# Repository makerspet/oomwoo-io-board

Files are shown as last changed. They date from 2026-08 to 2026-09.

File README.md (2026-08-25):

<div align="center">

# OOMWOO I/O Board

*Open-source robot vacuum you build yourself.*

Raspberry Pi CM4/CM5 socket · STM32G473 MCU · Motor drivers · Sensors · 2x MIPI cameras · 4S charging · KiCad





</div>

Part of [OOMWOO open-source robot vacuum](https://github.com/makerspet/oomwoo) project.

oomwoo_main_pcb_placement

Get [MCU firmware](https://github.com/makerspet/oomwoo-io-firmware/).

## Architecture notes

Consumer vacuums typically split compute into CPU and MCU. The MCU ([real examples](https://robotinfo.dev/)) controls
- all motors - driving wheels, suction fan, side brushes, mop motors, mop lift servos, pump and so on
- all sensors except below - IR cliff, IR side proximity, IR docking, wheel drop, bumper (IR or micro-switches), motor encoders, ultrasonic carpet sensor
- all push buttons
- 2D LiDAR motor RPM
- power - battery charging, motors power on/off
- all safety sensors - overcurrent for all motors (cheap vacuums ignore overcurrent sensing)

I/O board also provides audio encoders/decoders, amp, speaker (connector), mics (if any).

CPU receives
- 2D LiDAR data over serial port
- IMU (sometimes IMU gets forwarded via MCU) over SPI/I2C
- cameras (2x MIPI for visual obstacle avoidance)

MCU (and CPU) are usually always active. This allows the user to start cleaning at any time (especially via app remotely). Exceptions:
- no power (battery dead and no dock power)
- user explicitly shut down the vacuum by long-pressing the power button

The MCU's overarching constraint is to ensure robot safety. This is necessary to pass CE mark tests. Here is how MCU ensures safety:
- MCU firmware uses FreeRTOS or similar, static memory allocation, watchdog, guaranteed reaction time
- MCU acts as watchdog for CPU, resets CPU if CPU becomes unresponsive
- MCU connects to CPU over serial using a custom serial protocol ([concrete example](https://github.com/codetiger/VacuumRobot)). No micro-ROS to reduce dependencies, prevent bugs from updated 3rd party libraries slipping into safety-critical MCU firmware.
- MCU shuts down some (or all) motors when MCU detects overcurrent (brush stuck)
- MCU shuts down all motors (including power to all motors) when CPU becomes unresponsive (to prevent CPU sending garbage commands to MCU)
- MCU monitors battery charging, shuts it down when needed (battery too hot)
- MCU stops driving wheel motors when bumper sensors activate
- MCU tests motors, sensors
- MCU does not depend on CPU
- MCU toggles watchdog GPIO; otherwise an external-to-MCU circuit shuts down motor power

Consumer vacuums place CPU and MCU on the same PCB board. Since OOMWOO has to be hackable, it seems best to separate I/O from the compute. Therefore, this I/O board needs to have
- MCU and programming header
  - likely STM32G070RBT6 because it has 56 GPIOs, 16 ADC channels, costs $1 at JLCPCB, has LQFP package for easy PCBA - a rare combination
  - see tentative [I/O board spec](https://github.com/makerspet/oomwoo-io-board/blob/main/docs/SPEC.md)
- all vacuum motor drivers (with connectors), driven by the MCU
  - cliff, side proximity, docking, bumper, carpet, water tank full/empty, dust bin present, motor overcurrent, motor encoders
- MCU connected to all sensors (except those handled by CPU like LiDAR serial, MIPI cameras I/O, IMU); sensor connectors
- control circuit for 2D LiDAR's motor (controlled by MCU)
- battery charging, power management (motors power on/off, charging on/off, power shut down), power for CPU compute module (see below)
- push buttons (home, power, etc.) and UI LEDs
- dock connector (dock power, sense dock present)
- USB power for charging; USB for serial shell, etc.
- audio encoder/decoder, audio amp, mics (if any)
- SD card for hacking, cheap large storage
- connect IMU FSYNC to MCU to synchronize MCU timestamps with IMU data streaming to CPU

Consumer vacuums usually don't have a CPU fan/heatsink because the vacuum's suction fan can (indirectly) cool the CPU/MCU PCB. Therefore, no CPU fan on this I/O board.

As far as compute - currently it seems best to use a Raspberry Pi CM4/CM5 compute module. Why?
- CM4/CM5 modules cost a bit less than a full Raspberry Pi 4/5
- CM4/CM5 have lower profile/height vs a full Raspberry Pi 4/5, important to keep vacuum cleaner slim
- there are plenty of 3rd party compute modules pin-compatible with CM4/CM5, making the compute swappable, hackable
  - 3rd party compute modules with NPUs are especially interesting because we need NPU for real-time camera-based obstacle detection

Compute module headers should expose
- 2x MIPI camera I/O
- 1x serial for CPU-MCU comms
- 1x serial for CPU-LiDAR comms
- 1x SPI (or I2C) for CPU-IMU comms
- audio (digital?) I/O
- power from I/O board to CM
- a few TBD GPIOs
  - MCU GPIO to reset CPU

This board should be designed using an open-source PCB tool (KiCad seems like a good choice).

## License

[Apache License 2.0](LICENSE).

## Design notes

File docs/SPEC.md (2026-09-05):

# OOMWOO I/O Board spec (work in progress)

See [vacuum BOM](https://github.com/makerspet/oomwoo/blob/main/BOM.md) for details.

## Motors

Most motors draw power directly from the 4S battery (not via a DC-DC converter). The battery is 14.4V nominal, 12V discharged and 16.8V fully charged.

| Type | Qty | Spec |
| --- | --- | --- |
| Drive wheel | 2 | DC 14.4V 19 Ohm, measured 0.14A no load / 1.7A stall, H-bridge DRV8231, DRV8871 or similar |
| Suction fan | 1 | BLDC 14.4V, measured 1.7A free / 2.7A intake blocked (BL24131607 at 15V), high-side load switch P-FET, PWM input to fan, FG feedback to STM32 |
| LiDAR | 1 | 5V 0.35A max, Mabuchi-style RF-500TB-14350 or similar, low-side load switch N-FET |
| Main brush | 1 | DC 14.4-15V, measured 0.26A no load / 3.5A stall, PRI-390SV-24100, JLS-395PH-2248A, RS-390WM-3107GCF or similar (bridge or FET TBD) |
| Side brush | 1 | DC 14.4V, 1.3A stall estimated (not yet measured), RC500-KW/14440/DV, PR-500EV-14440 or similar (bridge or FET TBD) |
| Mop | 2 | GM-RS385Y-24065 or similar, DC 14.4V |
| Mop lift | 1 | Likely MG90S servo |
| Mop arm | 1 | Likely MG90S servo |
| Water pump | 1 | TBD |
| Side brush arm | 1 | Likely MG90S servo |

Motor pinouts

```
Roborock S5 Max wheel assembly - JST ZH 1.5mm male 7p (mates board f)
  0.14A no load, 1.7A stall at 14.4V
  pin 7 wheel-drop-switch on
  pin 6 wheel-drop-switch com
  pin 5 orange Hall 3.3-5V
  pin 4 blue Hall signal OUT, open collector
  pin 3 brown Hall GND
  pin 2 MOT-
  pin 1 MOT+

BL24131607 suction fan DC 14.4V; 15V 1.7A unobstructed, 2.7A intake obstructed
 JST PH2.0 female 5p (mates m-m fan-to-board cable)
 pin 5 +  (VMOT)
 pin 4 -  (GND)
 pin 3 SP (PWM)
 pin 2 FG (TACH)
 pin 1 ID (20K pulldown to GND to detect fan presence, I believe)

DC 14.4-15V 4S suction fans:
- 20N704R990F
- MSD-C-3
- MSD-D
- 20N709U020
  JST PH2.0 female 4p (mates m-m fan-to-board cable)
  pin 4 VMOT
  pin 3 GND
  pin 2 PWM, low == off; drive at 5V?
  pin 1 TACH open collector

22N704V160 suction fan DC 14.4V - JST PA 2mm 5 pin (needs male)

BL27302101 suction fan DC 14.4V - JST PA 2mm 6-pin (needs male)
  pin 1 VCC
  pin 2 VCC
  pin 3 GND
  pin 4 GND
  pin 5 PWM
  pin 6 FG (TACH)

BL24131616 suction fan DC 14.4V - JST PA 2mm 5 pin  (needs male)
  pin 5 VM
  pin 4 GND
  pin 3 PWM
  pin 2 FG (TACH)
  pin 1 ID

MSD-G-V1 suction fan - LHE MX3.0 2x2 (4-pin) 3mm pitch with latch male (aka Molex Micro-Fit 3.0)
```

Main brush Roborock S50 S51 S55 XIAOWA C10 0.26A no load, stall 3.5A at 14.4V

## Cliff sensors

JST PAD 2.0mm 8x2 housing, mates JST S16B-PHDSS, JST B16B-PADSS.

## Compute + Camera

- 2x 15-pin ArduCam-style connectors for OV5647
- TODO add USB to I/O board

Undecided TODO 
- maybe provision an M.2 slot, route a PICe lane, populate later - to experiment with NPU accelerator(s) like Hailo
- USB-C 3.0+, CM5 only - to experiment with accelerator(s) like Coral TPU
- Keep the compute socket able to take an integrated-NPU module too (Radxa CM5) or premium-upgradeable (CM5 + M.2 Hailo).
- Flag it to the PCB contractor as a design item: M.2 E-key (WiFi) + an M.2 M-key/PCIe (NPU or NVMe), PCIe lane routing, and the thermal path for a few-watt accelerator in a suction-cooled enclosure

## Charging

View [BRR-2P4S-5200FL battery datasheet](https://images.thdstatic.com/catalog/pdfImages/55/55d2f7f6-2ed9-44ed-ab4e-fb20d231c897.pdf) as a sample.

```
Battery BRR-2P4S-5200 14.4V nominal - 4-pin 3mm pitch with latch male LHE MX3.0 (C3001-H04), Molex Micro-Fit 3.0
[o66o] 4321 BAT+ 10.7K/NTC 0.62M/ID GND
```

### Robot

- the robot has 2 power inputs: USB-C and dock
  - robot receives 20-24V fixed DC from the dock
  - USB-C power use PD, request 20-24 V minimum (to step it down to 4S battery)
  - optional PPS
  - if a low-power USB-C 5V, 9V or 15V brick source is attached (no 20V/PPS), either charge slowly (optional) through a boost path or cleanly refuse and signal "insufficient charger" rather than misbehaving
- robot requires 65W minimum input (from the dock) with system power-path charger (a charger IC with a SYS rail)
  - support the vacuum charging and Raspberry Pi running simultaneously
  - assume Raspberry Pi is always on (to handle user access over Wi-Fi at any time)
  - Pi 5 worst case ~25 W (5 V/5 A) + housekeeping ≈ up to ~25–30 W
  - Healthy charge ~40 W (~0.5C into the 75 Wh pack)
  - ~65–70 W total
- cap charge at ~0.5C regardless of charging adapter power

### Dock

- the dock is powered from an external certified 24/25.2 V DC brick (~200–350 W)
  - use external brick for safety, the dock enclosure only ever sees 24 V DC
  - reuse a 25.2 V stick-vac motor for auto-empty, e.g. Dreame M10-E-4 25.2 V/310 W
- the dock has only 2 contacts: DOCK+ and GND
  - dock contacts feed a fixed 24V+ DC
  - the dock detects load/robot presence, energizes DOCK+ only when robot is detected (reliably, after a couple of seconds)
  - dock contacts are spring loaded, gold-coated pogo pins ≥4 A, placed rear-vertical, above water line
- ambient fan(s) for mop drying
  - no hot mop dry for now
- 2x water pumps: clean-feed + dirty-evacuate
  - diaphragm, 12–24 V
- dock PCB
  - ESP32 (WiFi + BLE + control)
  - Pump/fan drivers (brushed DC)
  - IR beacon LEDs + driver
  - robot/load presence-detect + charging contact energize FET
  - Level sensors (float/capacitive) clean-low, dirty-full
  - high-side FET for auto-empty blower
  - fuse, DC inlet, TVS
  - buck DC-DC 24V to 5V, 3.3V for ESP32, sensors

### Power path

Standard capability of power-path charger ICs - TI bq25 family and similar.

```
USB-C 20V ─► [PD sink] ─► [power-path charger] ─┬─► SYS rail ─► 14.4→5V buck ─► Pi (always-on)
                                                └─► charges 4S pack
Battery ────────────────────────────────────────┘ (supplements SYS if input insufficient)
```

- Docked: the Pi runs from the input via SYS; the battery charges from the surplus; once full, charge current → 0 and the Pi keeps running off input — no needless battery cycling while docked (also a longevity win).
- Undocked: SYS seamlessly falls back to the battery — the Pi never browns out during the handoff. This is exactly what makes "pause → return to charge → resume" and "app connects anytime" work cleanly.
- Input-limited: if only a weak brick is attached, the battery supplements SYS so the Pi stays up, and charge current backs off. Graceful degradation for free.

Details

1. 65 W = 20 V / 3.25 A → e-marked cable required. Above 3 A / 60 W, USB-C needs a 5 A e-marked cable. Unavoidable at 65 W (20 V is PD's max fixed voltage) — just document it. 65 W bricks ship with an e-marked cable anyway.
2. Dynamic power management (VIN/IIN-DPM): the charger must throttle charge current to keep total draw within the negotiated PD budget, prioritizing the Pi/SYS load. Standard on power-path chargers.
3. Cap charge current at ~0.5C (~2.6 A into the pack) for cell life, regardless of surplus — don't let a big brick fast-charge the cells.
4. Two DC inputs, one charger: the robot's own USB-C port and the dock contacts both present ~20 V DC → OR them into the charger's VBUS with priority/ideal-diode selection (both are the same voltage, so it's clean).
5. Dock side: dock has its own PD sink + 65 W brick, passes ~20 V to the contacts. At 20 V, 65 W ≈ 3.25 A over the contacts → size the pogo/spring contacts for ~4 A with margin.

Net spec

1. USB-C PD, 65 W minimum (20 V / 3.25 A), on both the robot port and the dock (each with its own PD sink); e-marked cable expected.
2. Power-path 4S charger with a SYS rail feeding the Pi's 5 V buck, so the Pi is always-on from input when docked and from battery when not, with seamless handoff and battery-supplement under load.
3. DPM + 0.5C charge-current cap; OR the two DC inputs into one VBUS; dock contacts rated ~4 A.

## LiDAR pinouts

```
X-WPFTB-V2.6.2 PCB marking - JST GH 1.25mm 4-pin female (needs m)

D-WPFTBCD-V1.0.1 PCB marking - JST GH 1.25mm 4-pin female (needs m)

LDROBOT LD14P lookalike - JST GH 1.25mm 4-pin female (needs m)

Mystery mini - JST GH 1.25mm 5-pin female (needs m)
```

## Front sensors module board

- 2x VL53L7CH (or VL53L7CX) 60° horizontal FoV each
  - each turned 30° left, right to cover 120° horizontal FoV
- 2x OV5647, 5M wide-angle for stereo depth + object recognition
  - off-the-shelf breakout boards for now
  - possibly $2 imaging ICs later
- NIR illumination LEDs with a projection pattern
- breaks into multiple PCBs using holes
  - central - 2x TSOP38238 (separated by a baffle) for dock homing
  - left - VL53L7CH pointed 30° left
  - right - VL53L7CH pointed 30° right
  - stereo depth camera 2x OV5647 with NIR illumination LEDs

## Side sensors module board

- TSOP38238 for dock detection
- consumer vacuums use analog Sharp short-range distance sensor
  - use VL6180V1NR/1 C2655167 $1.03 100pcs 18° FoV diagonal? Obsolete, similar to VL53L4CD
  - use VL53L0CX GY-530, TMF8806 or similar instead? Dust may be an issue.
  - VL53L0CXV0DH/1 C91199 $2.11 100pcs
  - VL53L4CDV0DH/1 C3178291 $2.19 100pcs

## Sensors

- VL53L7CH
  - Arduino library https://github.com/stm32duino/VL53L7CH
  - hookup schematic https://eu.mouser.com/en/new/stmicroelectronics/stm-vl53l7ch-tof-sensor
  - LPn pin sets I2C address

## Pump

- 6V DC motor, peristaltic; ~0.6A rated, 1A max
- make DC settable by replacing resistors

## GPIO

Please see the [PCB schematic](https://github.com/makerspet/oomwoo-io-board/tree/main/kicad/PDF) for up-to-date GPIO list.

TODO before layout/fabrication: confirm whether GPIO entries 36 and 46 are intentionally separate bumper inputs or a duplicate label.

## Carpet sensors

- Read [sourcing notes](https://makerspet.com/blog/how-to-source-bom-for-oomwoo-open-source-vacuum-robot/#carpet-sensor).
- 290KHz ultrasonic piezoelectric analog, likely [this one](https://htwsensor.en.made-in-china.com/product/HfMYgjwoZxVh/China-300kHz-Carpet-Material-Recognition-Sensor-for-Robotic-Vacuum-Cleaner-Ultraosinc-Sensor.html)

How to drive
- ≥12V DC stabilized per spec (not 4S battery directly?)
- connect to MCU ADC input
  - use STM32G473VCT6 internal op-amp as echo input (AC via a cap)
  - clamp amplitude to 3.3V (back-to-back clamp diodes, series resistor)
  - bias the MCU internal op-amp to Vref/2 using MCU internal DAC
  - configure ADC pre-amp gain, PGA mode (op-amp bandwidth is 10MHz)
  - configure op-amp to output signal to internal ADC channel
- FET half-bridge driven by MCU
  - drive the sensor for a brief while
  - tristate both FETs
  - measure using ADC, calculate return amplitude
  - calibrate return amplitude when docked
- 2-pin connector "1.25mm Y" per spec, exact model unclear
  - not Molex PicoBlade 1.25mm, not JST GH 1.25mm

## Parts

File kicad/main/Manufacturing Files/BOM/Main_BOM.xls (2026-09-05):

Comments | Designator | Footprint | LCSC | Note
150pF/50V | C7,C101,C105 | Capacitor_SMD:C_0603_1608Metric
22pF/50V | C34,C35 | Capacitor_SMD:C_0603_1608Metric
18pF/10V | C39,C42 | Capacitor_SMD:C_0603_1608Metric
330pF/25V | C47,C58 | Capacitor_SMD:C_0603_1608Metric
47nF/50V | C75,C79,C110 | Capacitor_SMD:C_0603_1608Metric
1nF/50V | C77,C125,C126 | Capacitor_SMD:C_0603_1608Metric
10k | R1,R18,R21,R22,R23,R25,R31,R32,R34,R36,R38,R39,R41,R42,R44,R45,R49,R50,R51,R52,R81,R92,R93,R110,R132,R142,R150,R152 | Resistor_SMD:R_0603_1608Metric
47k | R2,R7,R61,R62,R151 | Resistor_SMD:R_0603_1608Metric
100k | R3,R4,R8,R10,R11,R13,R16,R17,R20,R27,R29,R40,R43,R48,R53,R54,R55,R57,R58,R59,R115,R116,R118,R128,R130,R133,R135,R138,R139,R153 | Resistor_SMD:R_0603_1608Metric
2.2k | R5,R6,R15,R149 | Resistor_SMD:R_0603_1608Metric
0 | R9,R12,R19 | Resistor_SMD:R_0603_1608Metric
1k | R14,R28,R37,R65,R77,R78,R79,R82,R85,R113,R120,R121,R140 | Resistor_SMD:R_0603_1608Metric
330 | R30,R35 | Resistor_SMD:R_0603_1608Metric
20k | R47,R131,R147 | Resistor_SMD:R_0603_1608Metric
30.31k | R60 | Resistor_SMD:R_0603_1608Metric
10 | R64,R73,R74,R80,R94,R95,R96,R101,R117,R141,R146,R154 | Resistor_SMD:R_0603_1608Metric
100 | R75,R76,R100,R158 | Resistor_SMD:R_0805_2012Metric
5.24k | R127,R136,R137 | Resistor_SMD:R_0603_1608Metric
12k | R143,R148,R155 | Resistor_SMD:R_0603_1608Metric
69.8k | R144,R156 | Resistor_SMD:R_0603_1608Metric
22.1k | R145,R157 | Resistor_SMD:R_0603_1608Metric
1.2nF/50V | C112,C120,C130 | Capacitor_SMD:C_0603_1608Metric
100nF/50V | C1,C2,C4,C5,C9,C10,C12,C13,C14,C15,C16,C23,C28,C29,C30,C32,C37,C50,C56,C59,C61,C64,C65,C73,C84,C88,C92,C102,C103,C107,C109,C111,C117,C118,C119,C127,C128,C129,C142,C143 | Capacitor_SMD:C_0603_1608Metric
ComputeModule5-CM5 | Module1 | CM5IO:Raspberry-Pi-5-Compute-Module | 2X C6932320 | Install 2 × C6932320 connectors for CM5
AO3401 | Q8 | oomwoo_altium:SOT23-3D | C15127
TPS3828-33DBVR | U2 | JLCImport:TPS3828-33DBVR | C20032
NCP1117ST33T3G | U1 | NCP1117ST33T3G:SOT230P700X180-4N | C26537
DRV8870DDAR | U14,U15,U18,U20 | JLCImport:DRV8870DDAR | C86590
10uF/25V | C3,C6,C11,C17,C19,C31,C33,C45,C60,C62,C63,C66,C67,C68,C69,C70,C71,C72,C74,C76,C78,C80,C81,C82,C83,C90,C91,C94,C95,C96,C97,C98,C99,C100,C104,C106,C108,C113,C114,C115,C116,C121,C122,C123,C124,C131,C132,C133,C134,C135,C136,C137,C138,C139,C140,C141,C144,C145,C146,C147 | Capacitor_SMD:C_0603_1608Metric | C96446
TPD2EUSB30DRTR | D34 | TPD2EUSB30DRTR:SOTFL35P100X50-3N | C97502
ABM3-8_000MHZ-D2Y-T | X1 | JLCImport:ABM3-8_000MHZ-D2Y-T | C144380
SMAJ18A_C148219 | D3 | JLCImport:SMAJ18A_C148219 | C148219
S16B-PHDSS_LF_SN | BUMP_CLIFF1 | JLCImport:S16B-PHDSS_LF_SN | C161675
215k | R99 | Resistor_SMD:R_0603_1608Metric | C185443
EV2400 | CN2 | JLCImport:A2543WV-4P | C239364
RT9742GGJ5 | U6 | JLCImport:RT9742GGJ5 | C250547
17.4k | R129 | Resistor_SMD:R_0603_1608Metric | C327366
BZT52C12T-7 | D39,D40 | JLCImport:BZT52C12T-7 | C507911
TVS2200DRVR | D1,D2 | JLCImport:TVS2200DRVR | C523793
BATTERY | BAT2 | JLCImport:436500412 | C563847
1-2199119-5 | J2 | 1-2199119-5:TE_1-2199119-5 | C574849
1040310811 | SDCARD2 | JLCImport:1040310811 | C585350
SQJ844AEP-T1_GE3 | Q4,Q21 | JLCImport:SQJ844AEP-T1_GE3 | C727613
STM32G473VCT6 | U13 | footprints:LQFP100-14x14mm | C730121
MAX98357AETE_T | U11 | JLCImport:MAX98357AETE_T | C910544
1N4148 | D24,D25,D26,D27,D28 | oomwoo_altium:SOD123 | C917030
AP64501SP-13 | U21,U22,U24 | JLCImport:AP64501SP-13 | C2071517
ASEK-32.768KHZ-LRT | Y1 | ASEK-32.768KHZ-LRT:XTAL_ASEK-32.768KHZ-LRT | C2650753
BQ25792RQMR | U7 | JLCImport:BQ25792RQMR | C2862876
1N4007 | D22 | oomwoo_altium:SOD123 | C2892681
WAFER-PH2_0-4PWB | CONTACT_CHGR1,MAIN_FAN1 | JLCImport:WAFER-PH2_0-4PWB | C3029442
SFW15R-1STE1LF | CAM0,MIPI0,MIPI1 | SFW15R-1STE1LF:AMPHENOL_SFW15R-1STE1LF | C3168538
BV1HAL45EFJ-E2 | U8,U23 | JLCImport:BV1HAL45EFJ-E2 | C3229246
PM254-2-06-S-8_5 | H1 | JLCImport:PM254-2-06-S-8_5 | C3975151
ICM-42607-P | U19 | JLCImport:ICM-42607-P | C5129967
CYA0630-3_3UH | L2,L3,L4 | JLCImport:CYA0630-3_3UH | C5189747
ESD5451N | ED3,ED4 | oomwoo_altium:ESD0402 | C5261080
0.2R/10W | R83,R84,R88,R112 | Resistor_SMD:R_2512_6332Metric | C5375488
STLINK-V3MINIE | JTAG1 | JLCImport:FTSH-107-01-L-DV-K-A | C5563894
ICS-43434_C5656610 | U9,U10 | JLCImport:ICS-43434_C5656610 | C5656610
2302V | Q1,Q2,Q5,Q6,Q7,Q9,Q10 | JLCImport:2302V | C7431443
TC-6601-5_0-260-8_3 | SW1,SW2,SW3 | JLCImport:TC-6601-5_0-260-8_3 | C7528752
XKXEL89CII-SUAYLC-32_768K | X3 | JLCImport:XKXEL89CII-SUAYLC-32_768K | C18214309
YLED0603B | CM_ACT1,CM_PWR1,HOME1,M2_ACT1,PWR1 | JLCImport:YLED0603B | C19171394
3V3-STM | D23 | oomwoo_altium:LED0603-B | C19171394
3V3-STAT | D29 | oomwoo_altium:LED0603-B | C19171394
ZX-ZH1_5-2PWT | LIGHT1,MAIN_BRUSH1,PUMP1,SIDE_BRUSH1,SPK1 | JLCImport:ZX-ZH1_5-2PWT | C19272405
ZX-ZH1_5-4PWT | IR-F1,IR-F2 | JLCImport:ZX-ZH1_5-4PWT | C19272407
ZX-ZH1_5-7PWT | MOT_WHEEL_L1,MOT_WHEEL_R1,SIDE-L1,SIDE-R1,VL-L1,VL-R1 | JLCImport:ZX-ZH1_5-7PWT | C19272410
AO3400 | Q20 | oomwoo_altium:SOT23-3D | C20628874
HC-PM254-8_5H-2X12PS | MCU_IO1 | JLCImport:HC-PM254-8_5H-2X12PS | C22436159
TPS25730DREFR | IC5 | LIB_TPS25730DREFR:TPS25730DREFR | C22438973
SS34 | D5,D6,D10,D37,D38 | Diode_SMD:D_SMA | C22448055
Conn_01x02_Pin | BOOT1 | Connector_PinHeader_2.54mm:PinHeader_1x02_P2.54mm_Vertical | C32713268
USB4215-03-A_REVA | USB2 | USB4215-03-A_REVA:GCT_USB4215-03-A_REVA | C37616412
HC-PM254-5_0H-2X4PS-02A | U3 | JLCImport:HC-PM254-5_0H-2X4PS-02A | C42163132
Conn_01x05_Pin | CONSOLE1,STM_DEBUG1 | Connector_PinHeader_2.54mm:PinHeader_1x05_P2.54mm_Vertical | C42431835
2N3906_C49023424 | Q12 | JLCImport:2N3906_C49023424 | C49023424
2N3904 | Q11 | oomwoo_altium:SOT23-3D | C50176433
1uH | L7 | JLCImport:GSM0420-1R0-M | C51933819

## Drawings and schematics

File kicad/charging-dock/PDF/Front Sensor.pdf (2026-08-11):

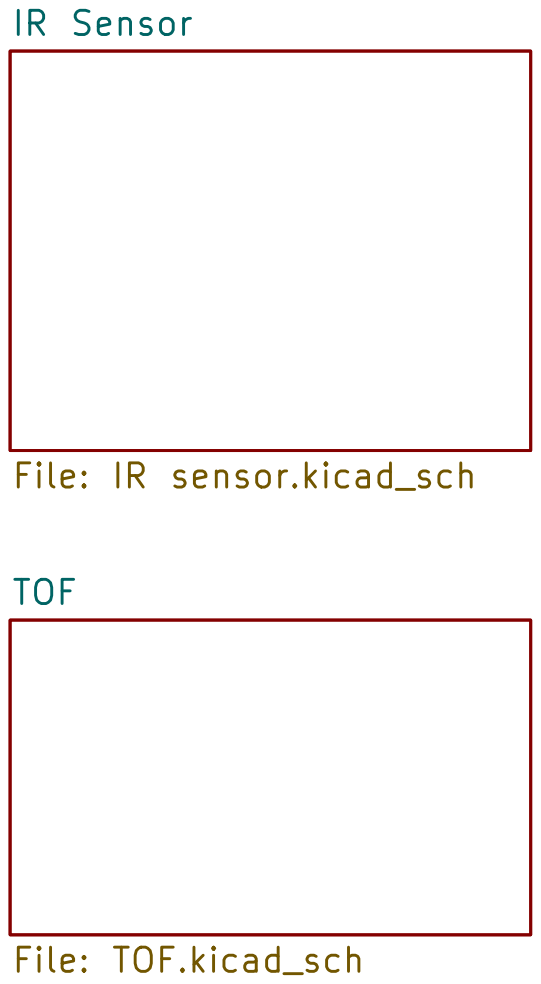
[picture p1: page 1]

IR Sensor File: IR sensor.kicad_sch

Size: A4 | Rev:
KiCad E.D.A. 10.0.3 | Id: 1/3

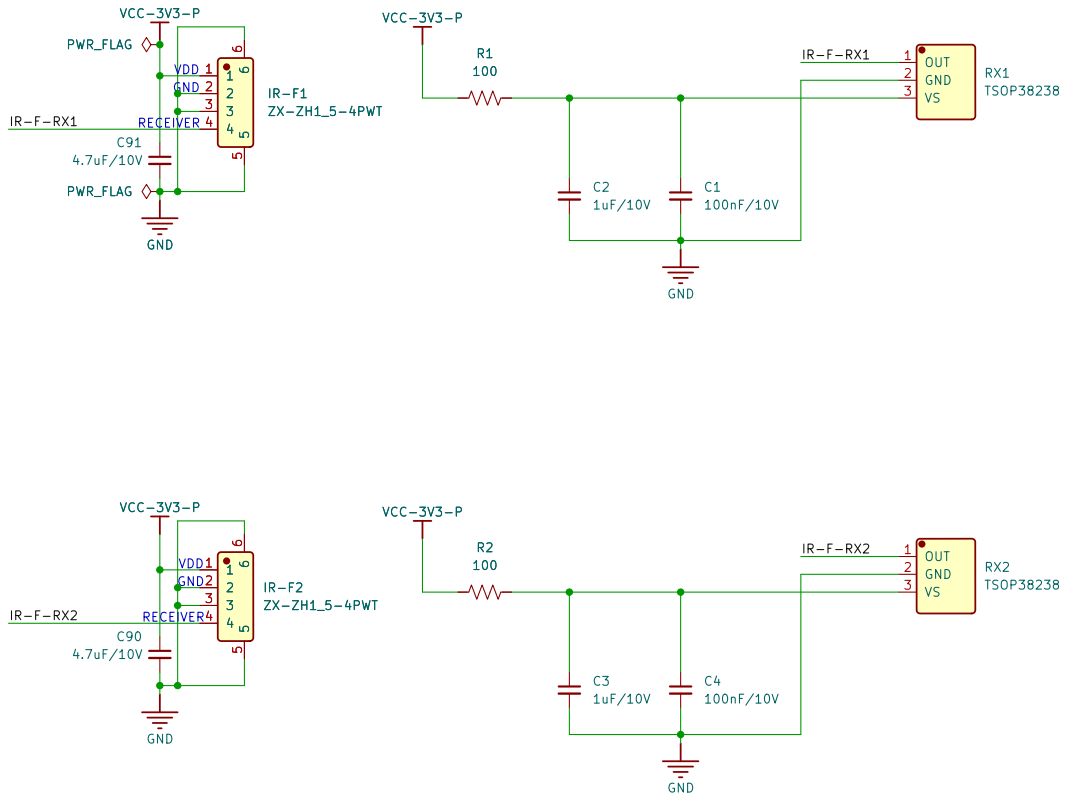
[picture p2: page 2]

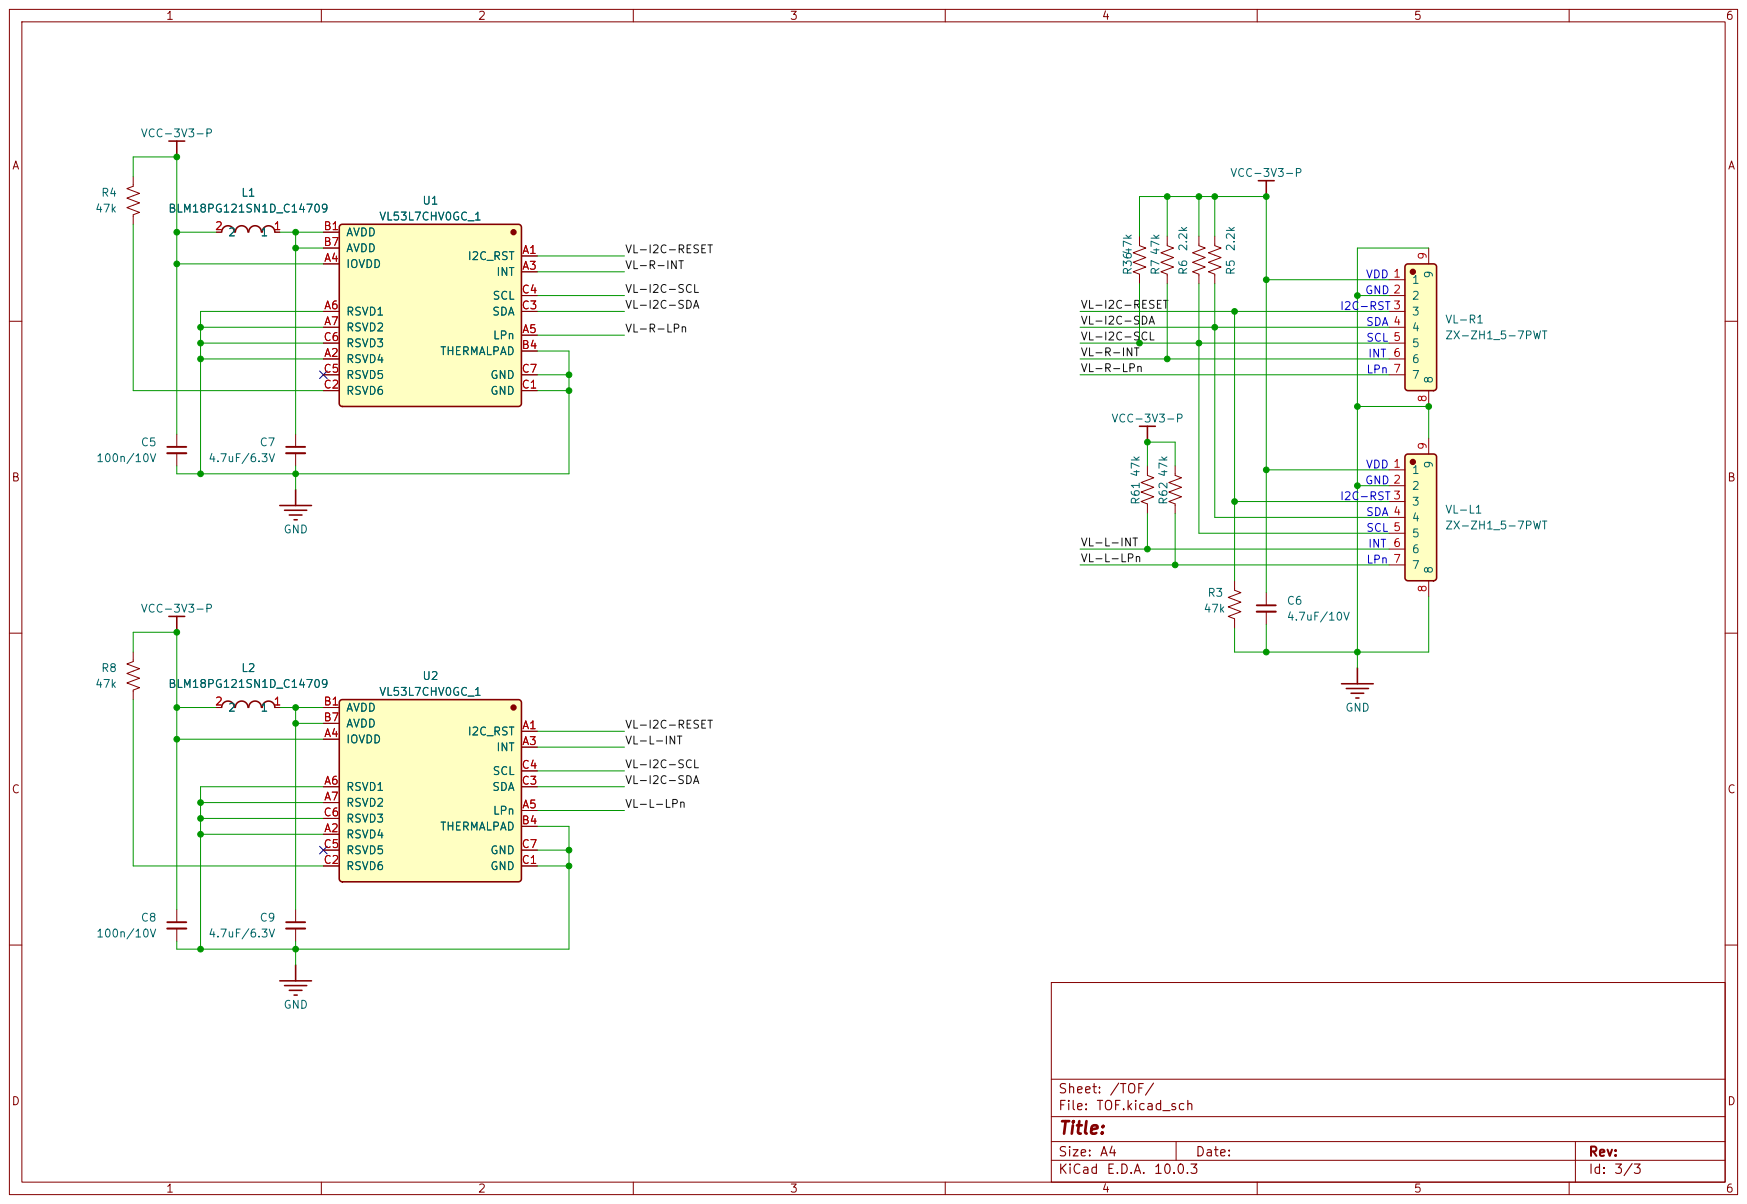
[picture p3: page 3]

VL-I2C-RESET VL-I2C-SDA
VL-R-INT VL-I2C-SCL VL-R-LPn

VL-R-INT VL-I2C-SCL VL-I2C-RESET VL-I2C-SDA

VL-L-INT VL-I2C-SDA

VL-I2C-RESET VL-I2C-SCL VL-L-INT

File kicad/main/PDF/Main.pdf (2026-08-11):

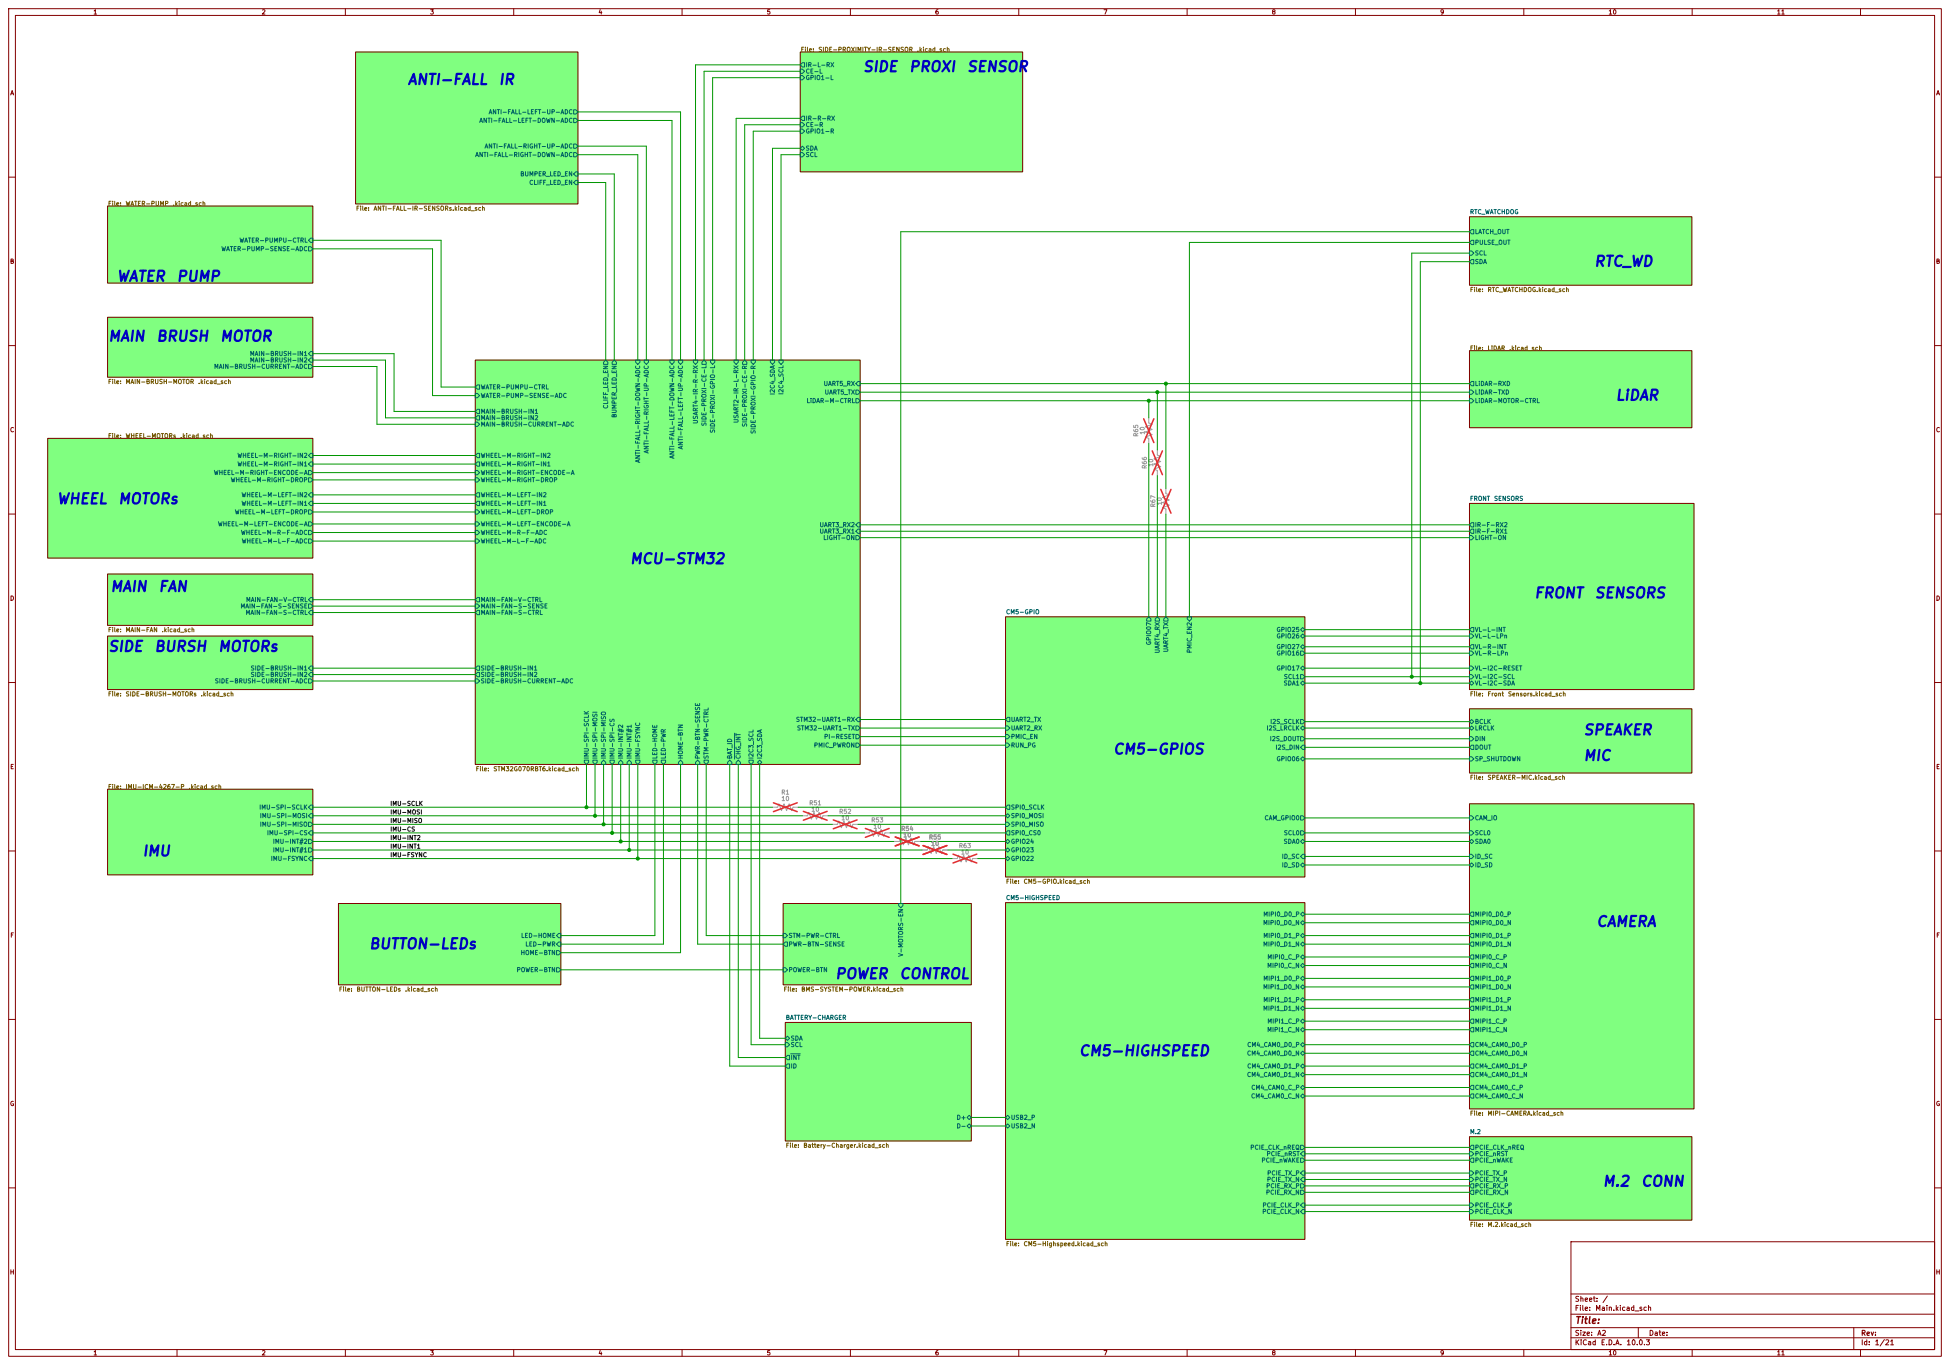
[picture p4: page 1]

ANTI-FALL-LEFT-UP-ADC
ANTI-FALL-LEFT-DOWN-ADC

ANTI-FALL-RIGHT-UP-ADC
ANTI-FALL-RIGHT-DOWN-ADC

File: ANTI-FALL-IR-SENSORs.kicad_sch

MAIN-BRUSH-CURRENT-ADC MAIN-BRUSH-IN1 MAIN-BRUSH-IN2

File: SPEAKER-MIC.kicad_sch WHEEL-M-RIGHT-IN2 WHEEL-M-RIGHT-IN1 WHEEL-M-RIGHT-ENCODE-A WHEEL-M-LEFT-IN2 WHEEL-M-LEFT-IN1 WHEEL-M-LEFT-ENCODE-A WHEEL-M-R-F-ADC WHEEL-M-L-F-ADC WHEEL-M-LEFT-DROP WHEEL-M-RIGHT-DROP

MAIN-FAN-V-CTRL MAIN-FAN-S-CTRL MAIN-FAN-S-SENSE

VL-L-INT VL-L-LPn

VL-R-INT VL-R-LPn

VL-I2C-RESET VL-I2C-SCL VL-I2C-SDA

SIDE-BRUSH-CURRENT-ADC

File: SIDE-BRUSH-MOTORs .kicad_sch

LED-HOME
LED-PWR HOME-BTN

File: CM5-Highspeed.kicad_sch POWER-BTN

File: BMS-SYSTEM-POWER.kicad_sch

Size: A2 | Rev:
KiCad E.D.A. 10.0.3 | Id: 1/21

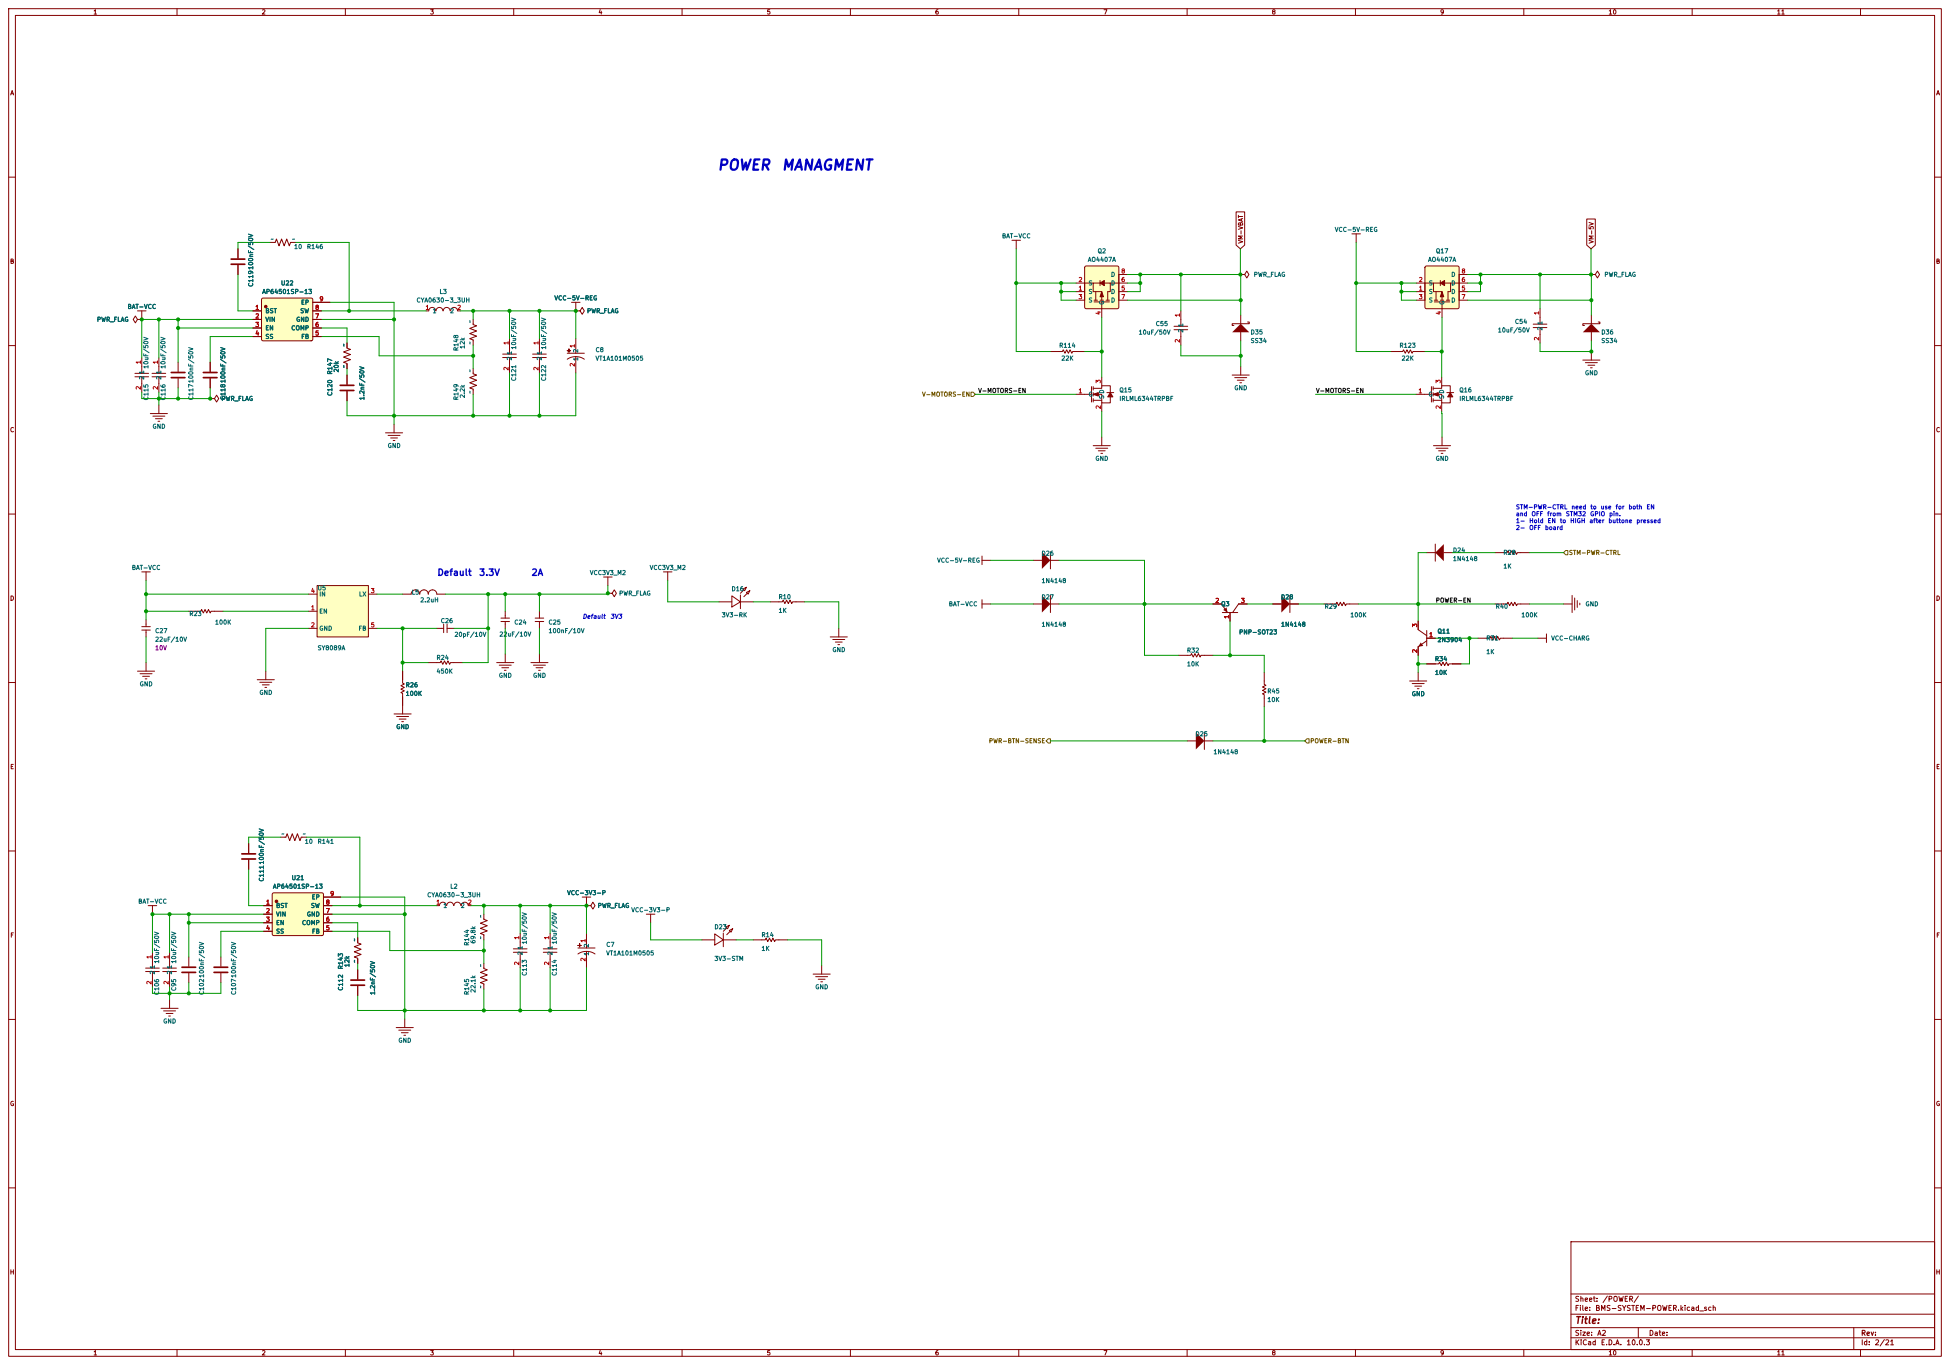
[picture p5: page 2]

STM-PWR-CTRL need to use for both EN

STM-PWR-CTRL POWER-BTN

Sheet: /POWER/
File: BMS-SYSTEM-POWER.kicad_sch

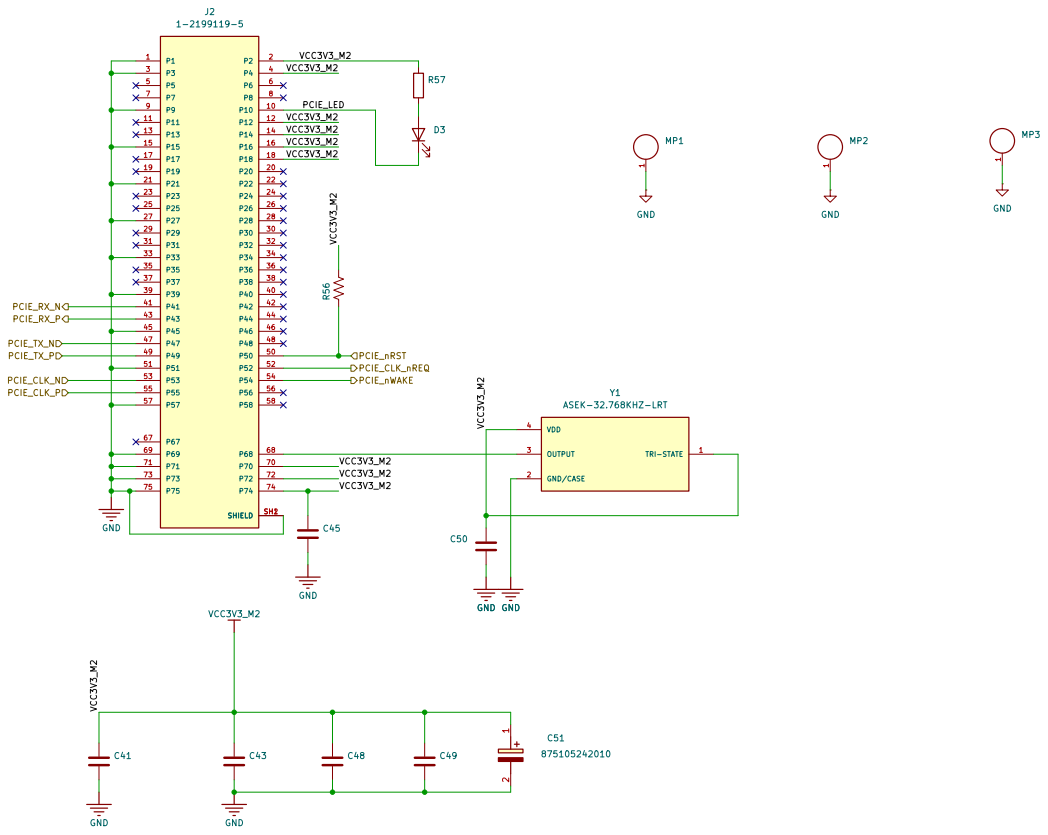
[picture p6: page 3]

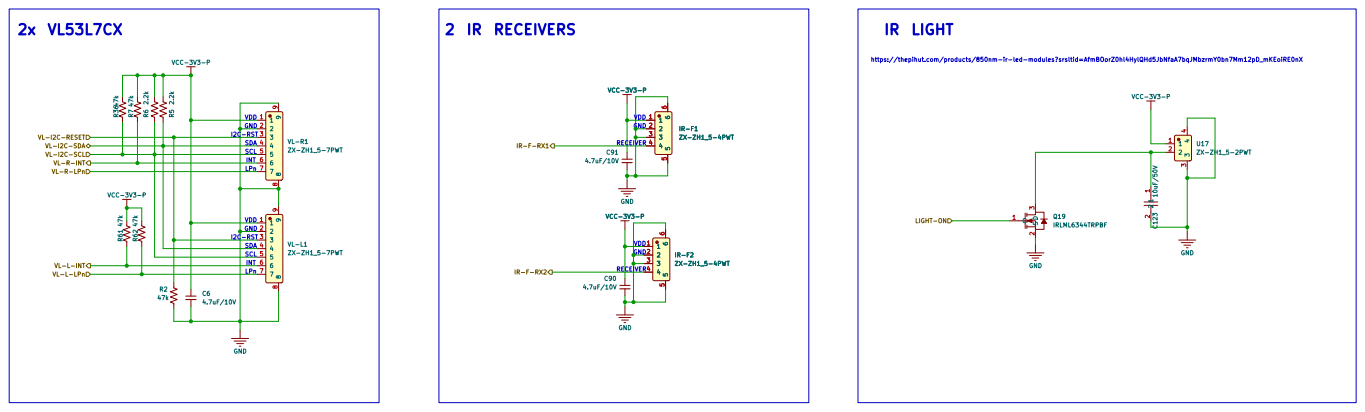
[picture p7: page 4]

https://thepihut.com/products/850nm-ir-led-modules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

VL-R-INT VL-I2C-SCL VL-I2C-SDA

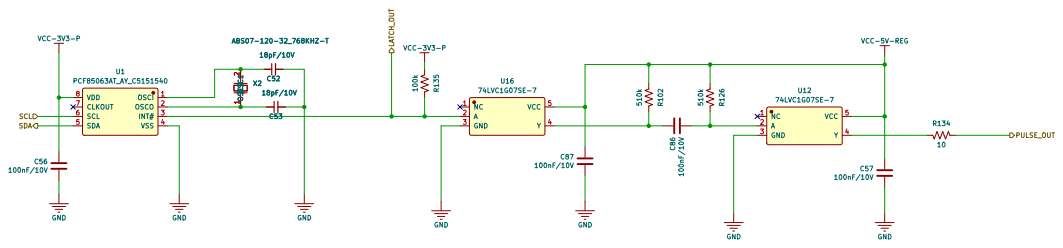
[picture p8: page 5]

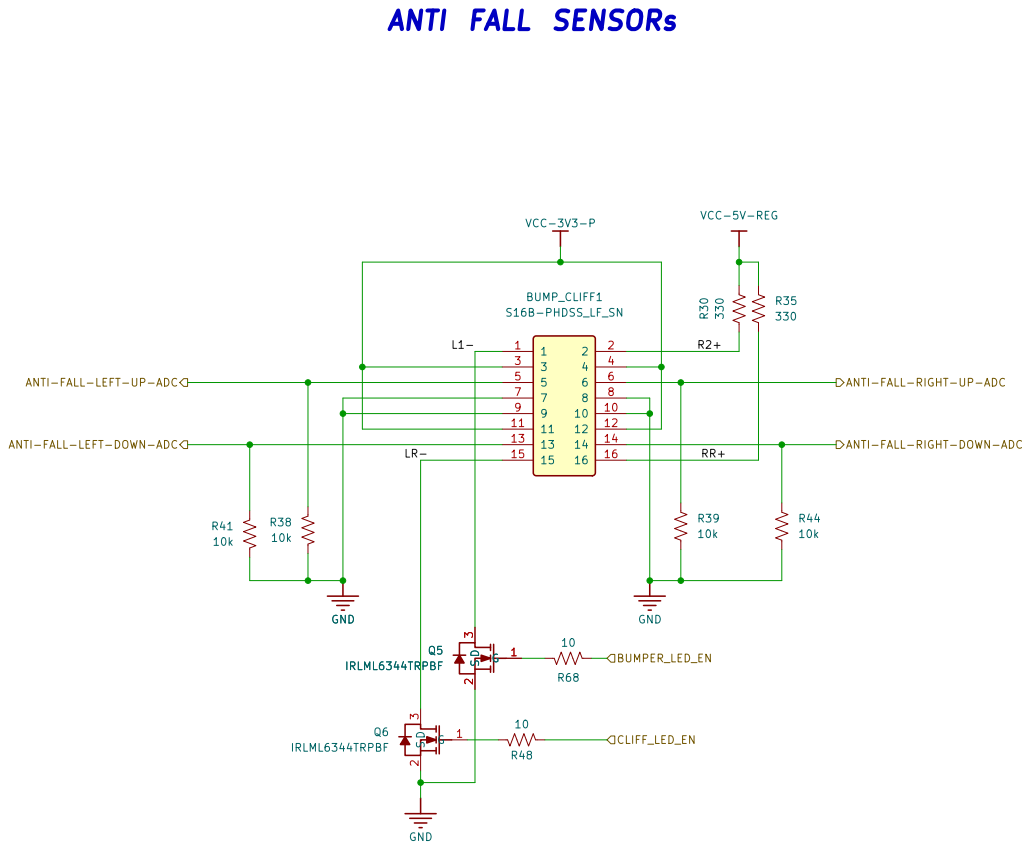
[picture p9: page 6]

Sheet: /ANTI-FALL/
File: ANTI-FALL-IR-SENSORs.kicad_sch

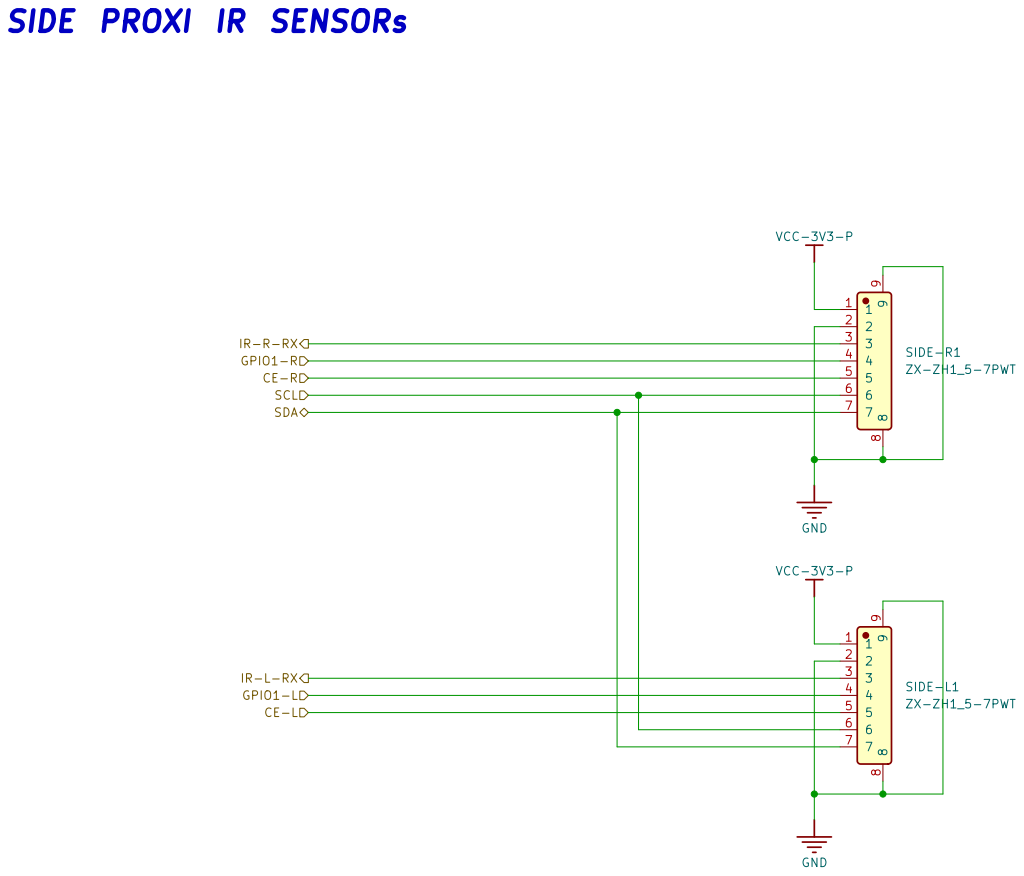
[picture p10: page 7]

SCL CE-L GPIO1-L SDA SIDE PROXI IR SENSORs

Sheet: /SIDE-PROXI/
File: SIDE-PROXIMITY-IR-SENSOR .kicad_sch

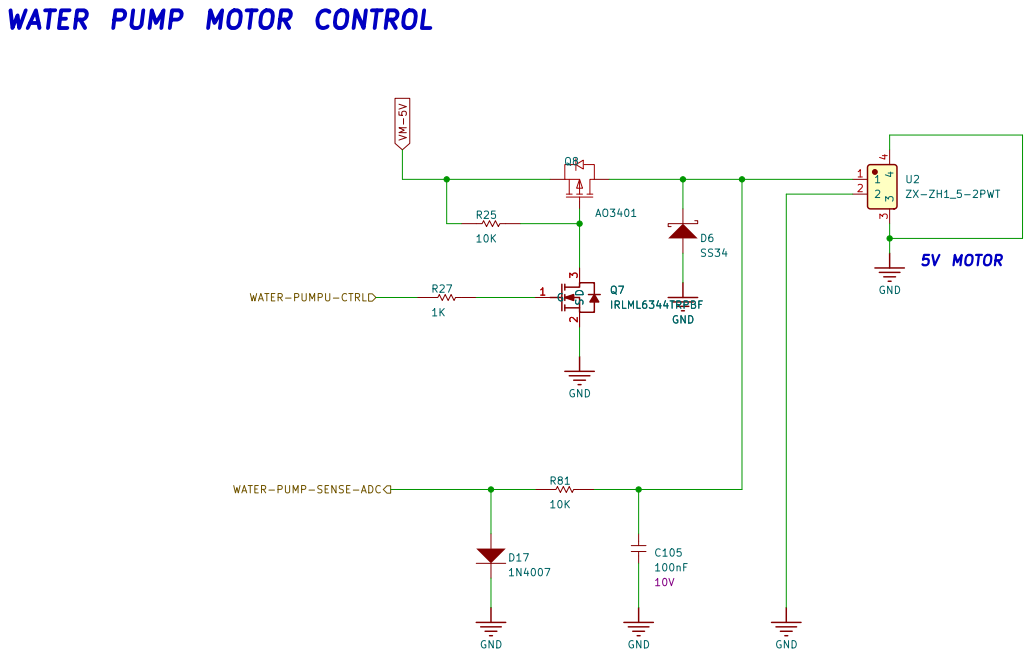
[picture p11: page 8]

WATER PUMP MOTOR CONTROL

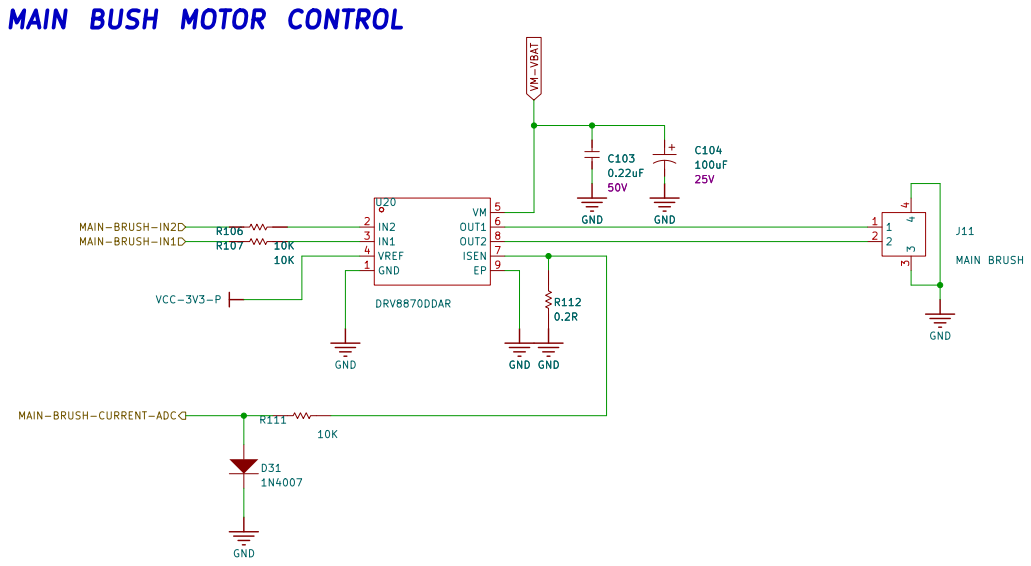
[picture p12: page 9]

MAIN BUSH MOTOR CONTROL

Sheet: /MAIN-BRUSH MOTOR/
File: MAIN-BRUSH-MOTOR .kicad_sch




SIDE-BRUSH MOTOR CONTROL

SIDE-BRUSH-CURRENT-ADC

Sheet: /SIDE-BRUSH/
File: SIDE-BRUSH-MOTORs .kicad_sch



RIGHT CHANNEL SELECTMicrophone Input


LED-PWR LEDs AND BUTTONs
LED-HOME D13



ANTI-FALL-LEFT-UP-ADC
ANTI-FALL-LEFT-DOWN-ADC WATER-PUMP-SENSE-ADC MAIN-BRUSH-CURRENT-ADC
ANTI-FALL-RIGHT-UP-ADC WHEEL-M-LEFT-IN2 WHEEL-M-RIGHT-DROP
ANTI-FALL-RIGHT-DOWN-ADC

IMU-SPI-CS HOME-BTN

49 49 | 48 48
64 64 | 63 63
75 75 | 74 74

LIGHT-ON WHEEL-M-L-F-ADC

Compatible with TTL-234X-3V3 smart cable



.Max Current= 5A BATTERY CHARGER

NOTE : D+ , D_ are connected to CM4/5 I Limit = 5 Amp

NOTE : SDA,SCL,nINT are connected to MCU


600mA Max 600mA Max NB SD signals are only available on modules without eMMC


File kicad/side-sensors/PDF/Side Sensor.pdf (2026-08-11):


IR Sensor File: IR sensor.kicad_sch

Size: A4 | Rev:
KiCad E.D.A. 10.0.3 | Id: 1/2


IR-RX-OUT SCL CESDA

Size: A4 | Rev:
KiCad E.D.A. 10.0.3 | Id: 2/2

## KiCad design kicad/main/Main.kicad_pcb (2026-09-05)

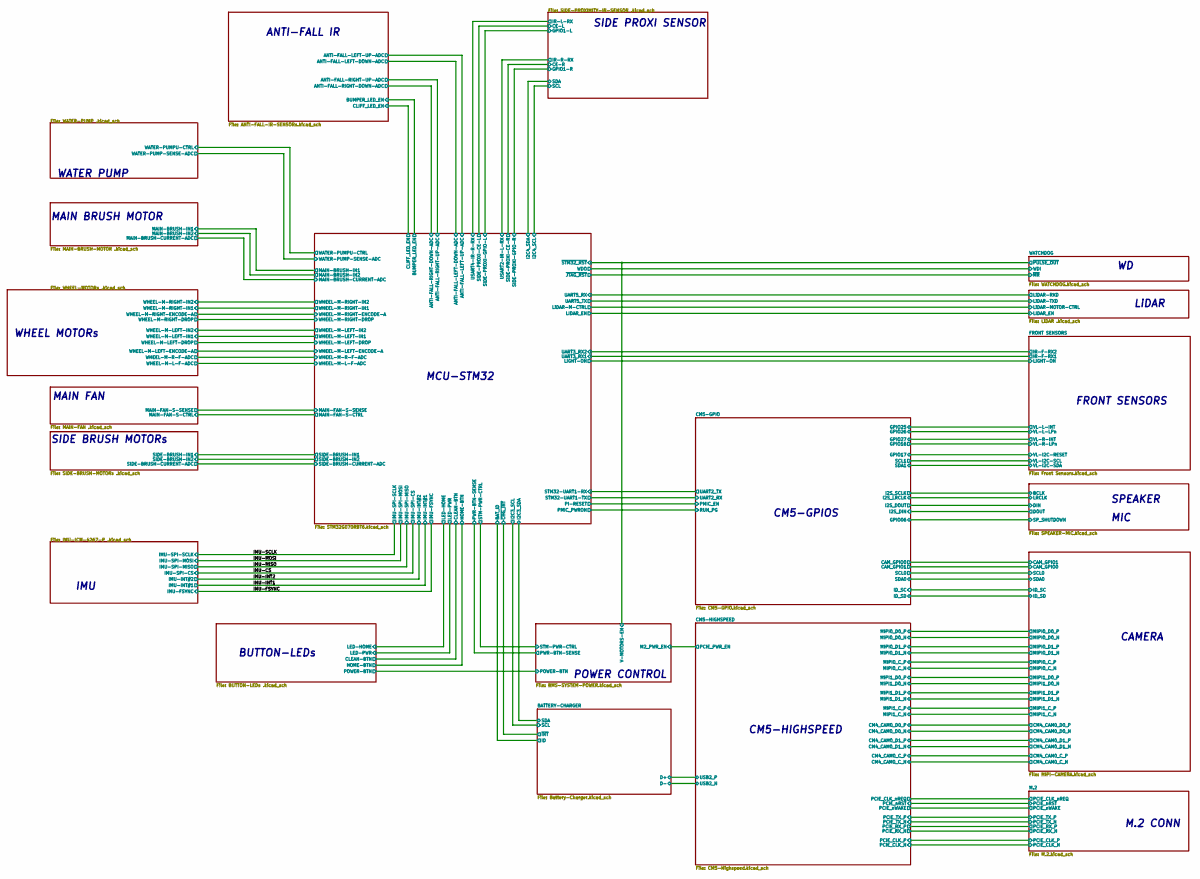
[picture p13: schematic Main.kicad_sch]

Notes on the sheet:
IMU
ANTI-FALL IR
WATER PUMP
FRONT SENSORS
M.2 CONN
CAMERA
MAIN FAN
BUTTON-LEDs
SIDE PROXI SENSOR
MCU-STM32
CM5-HIGHSPEED
SPEAKER
POWER CONTROL
WHEEL MOTORs
LiDAR
SIDE BRUSH MOTORs
MAIN BRUSH MOTOR
CM5-GPIOS
MIC

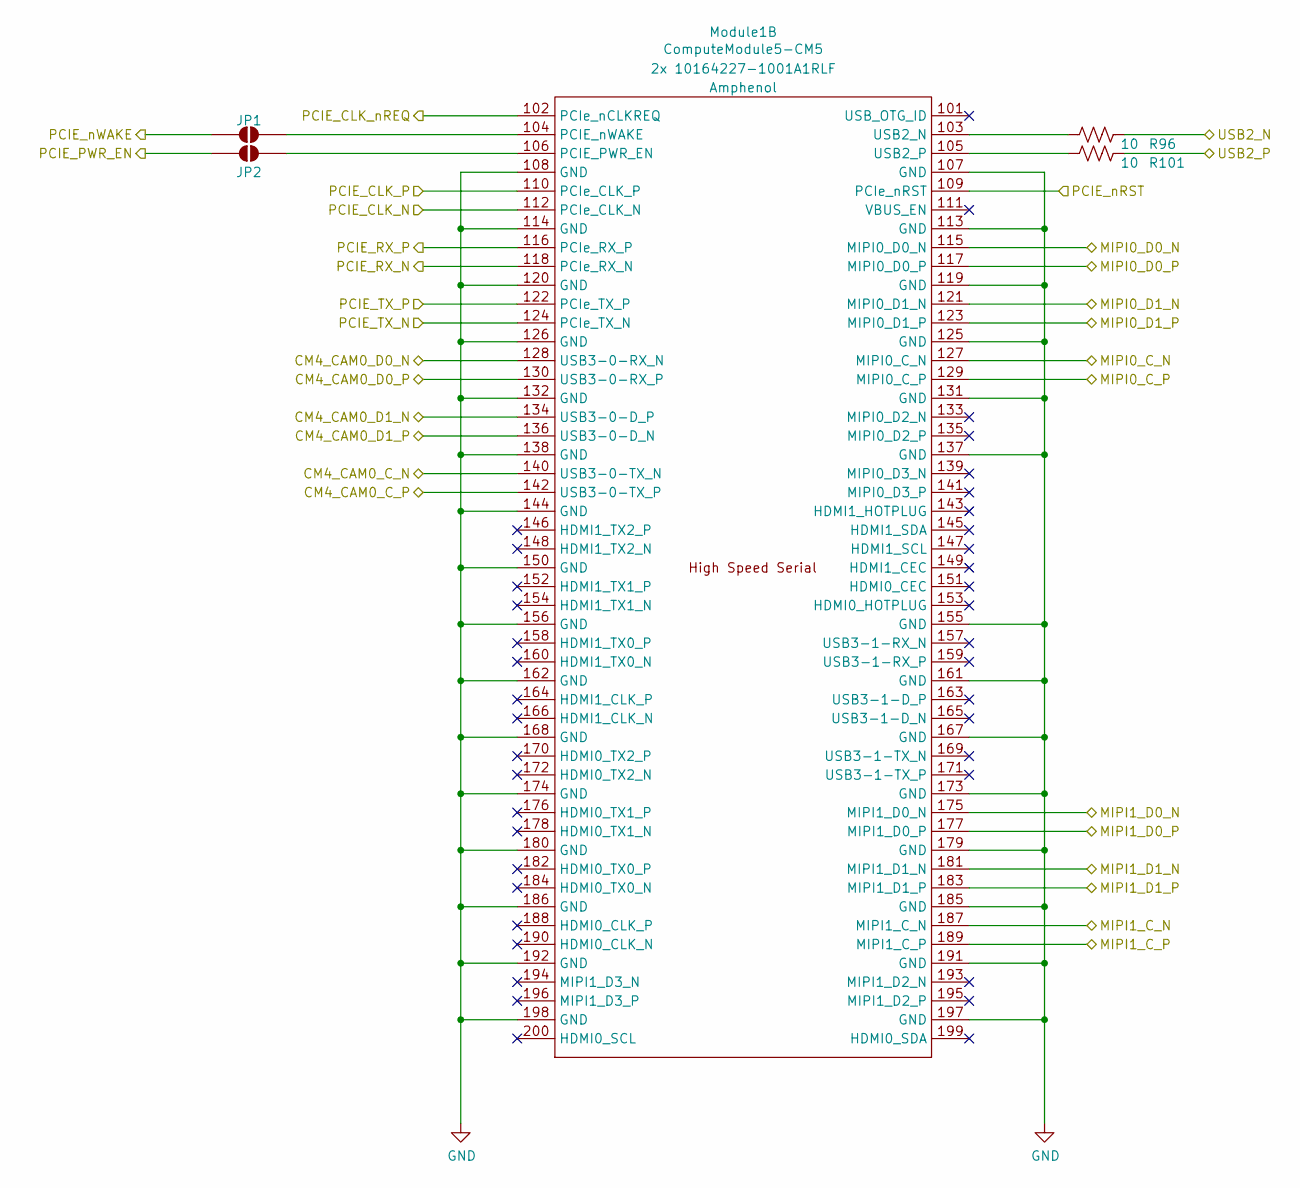
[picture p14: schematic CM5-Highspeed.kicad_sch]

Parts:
JP1, JP2: SolderJumper-2_P1.3mm_Open_RoundedPad1.0x1.5mm
Module1: ComputeModule5-CM5; Raspberry-Pi-5-Compute-Module; Part Description 100 Position Connector Receptacle, Cent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; LCSC 2X C6932320
R96, R101: 10; R_0603_1608Metric

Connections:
/BATTERY-CHARGER/D+: R101.2; also elsewhere on the board
/BATTERY-CHARGER/D-: R96.2; also elsewhere on the board
/CAMERA/CM4_CAM0_C_N: Module1.140 (USB3-0-TX_N); also elsewhere on the board
/CAMERA/CM4_CAM0_C_P: Module1.142 (USB3-0-TX_P); also elsewhere on the board
/CAMERA/CM4_CAM0_D0_N: Module1.128 (USB3-0-RX_N); also elsewhere on the board
/CAMERA/CM4_CAM0_D0_P: Module1.130 (USB3-0-RX_P); also elsewhere on the board
/CAMERA/CM4_CAM0_D1_N: Module1.134 (USB3-0-D_P); also elsewhere on the board
/CAMERA/CM4_CAM0_D1_P: Module1.136 (USB3-0-D_N); also elsewhere on the board
/CAMERA/MIPI0_C_N: Module1.127 (MIPI0_C_N); also elsewhere on the board
/CAMERA/MIPI0_C_P: Module1.129 (MIPI0_C_P); also elsewhere on the board
/CAMERA/MIPI0_D0_N: Module1.115 (MIPI0_D0_N); also elsewhere on the board
/CAMERA/MIPI0_D0_P: Module1.117 (MIPI0_D0_P); also elsewhere on the board
/CAMERA/MIPI0_D1_N: Module1.121 (MIPI0_D1_N); also elsewhere on the board
/CAMERA/MIPI0_D1_P: Module1.123 (MIPI0_D1_P); also elsewhere on the board
/CAMERA/MIPI1_C_N: Module1.187 (MIPI1_C_N); also elsewhere on the board
/CAMERA/MIPI1_C_P: Module1.189 (MIPI1_C_P); also elsewhere on the board
/CAMERA/MIPI1_D0_N: Module1.175 (MIPI1_D0_N); also elsewhere on the board
/CAMERA/MIPI1_D0_P: Module1.177 (MIPI1_D0_P); also elsewhere on the board
/CAMERA/MIPI1_D1_N: Module1.181 (MIPI1_D1_N); also elsewhere on the board
/CAMERA/MIPI1_D1_P: Module1.183 (MIPI1_D1_P); also elsewhere on the board
/CM5-HIGHSPEED/PCIE_CLK_N: Module1.112 (PCIe_CLK_N); also elsewhere on the board
/CM5-HIGHSPEED/PCIE_CLK_P: Module1.110 (PCIe_CLK_P); also elsewhere on the board
/CM5-HIGHSPEED/PCIE_CLK_nREQ: Module1.102 (PCIe_nCLKREQ); also elsewhere on the board
/CM5-HIGHSPEED/PCIE_PWR_EN: JP2.1 (A); also elsewhere on the board
/CM5-HIGHSPEED/PCIE_RX_N: Module1.118 (PCIe_RX_N); also elsewhere on the board
/CM5-HIGHSPEED/PCIE_RX_P: Module1.116 (PCIe_RX_P); also elsewhere on the board
/CM5-HIGHSPEED/PCIE_TX_N: Module1.124 (PCIe_TX_N); also elsewhere on the board
/CM5-HIGHSPEED/PCIE_TX_P: Module1.122 (PCIe_TX_P); also elsewhere on the board
/CM5-HIGHSPEED/PCIE_nRST: Module1.109 (PCIe_nRST); also elsewhere on the board
/CM5-HIGHSPEED/PCIE_nWAKE: JP1.1 (A); also elsewhere on the board
GND: Module1.107 (GND), Module1.108 (GND), Module1.113 (GND), Module1.114 (GND), Module1.119 (GND), Module1.120 (GND), Module1.125 (GND), Module1.126 (GND), Module1.131 (GND), Module1.132 (GND), Module1.137 (GND), Module1.138 (GND), Module1.144 (GND), Module1.150 (GND), Module1.155 (GND), Module1.156 (GND), Module1.161 (GND), Module1.162 (GND), Module1.167 (GND), Module1.168 (GND), Module1.173 (GND), Module1.174 (GND), Module1.179 (GND), Module1.180 (GND), Module1.185 (GND), Module1.186 (GND), Module1.191 (GND), Module1.192 (GND), Module1.197 (GND), Module1.198 (GND); also elsewhere on the board
unnamed: JP1.2 (B), Module1.104 (PCIE_nWAKE)
unnamed: JP2.2 (B), Module1.106 (PCIE_PWR_EN)
unnamed: Module1.103 (USB2_N), R96.1
unnamed: Module1.105 (USB2_P), R101.1

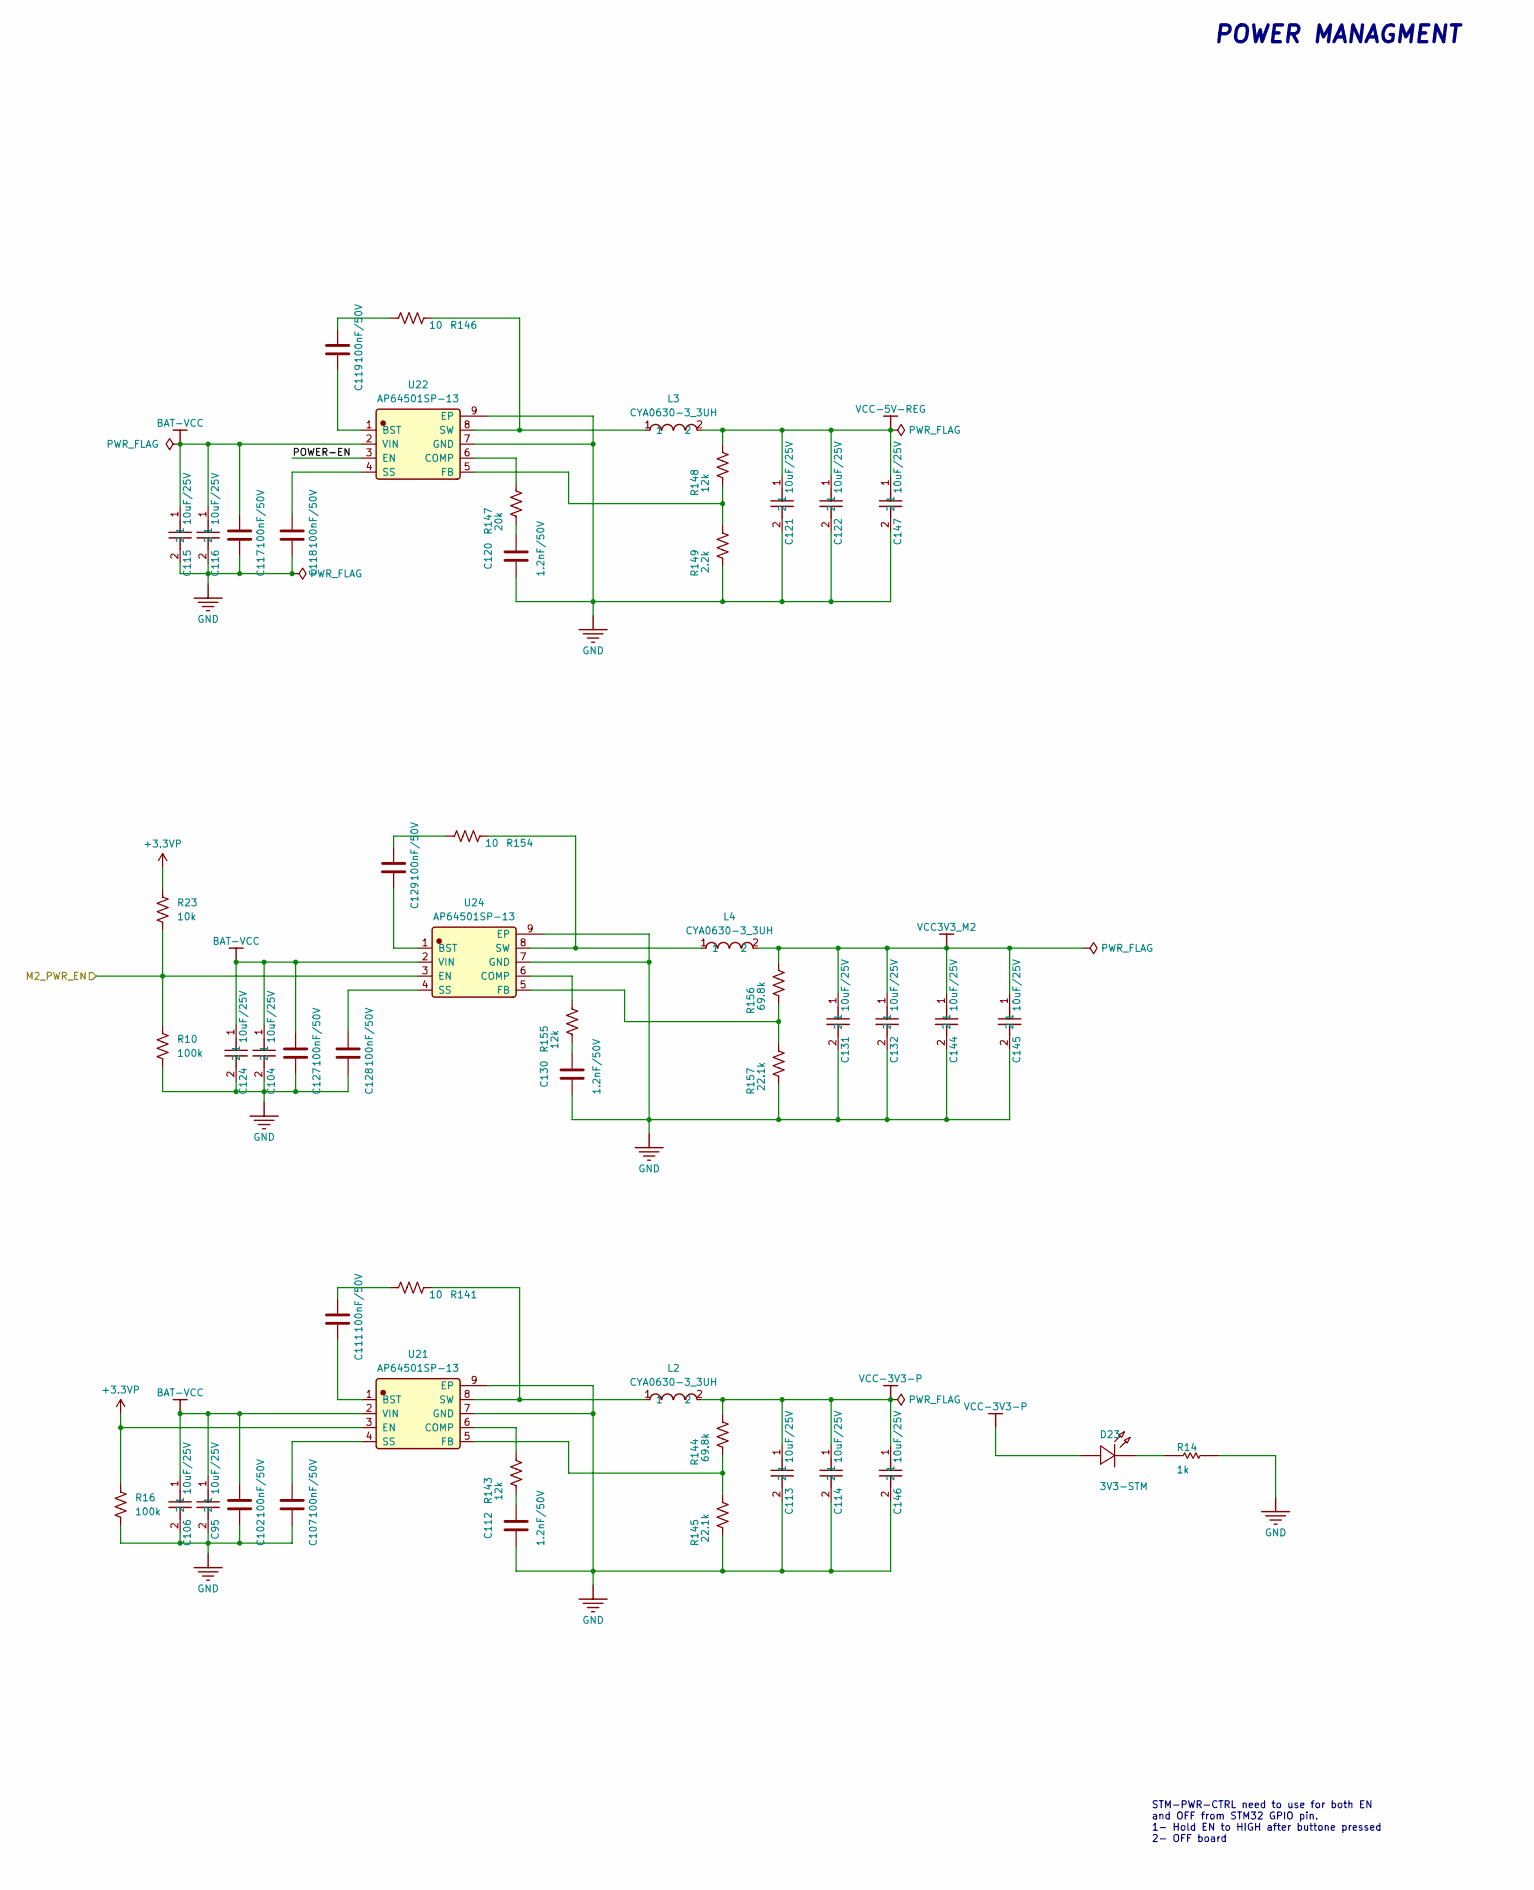
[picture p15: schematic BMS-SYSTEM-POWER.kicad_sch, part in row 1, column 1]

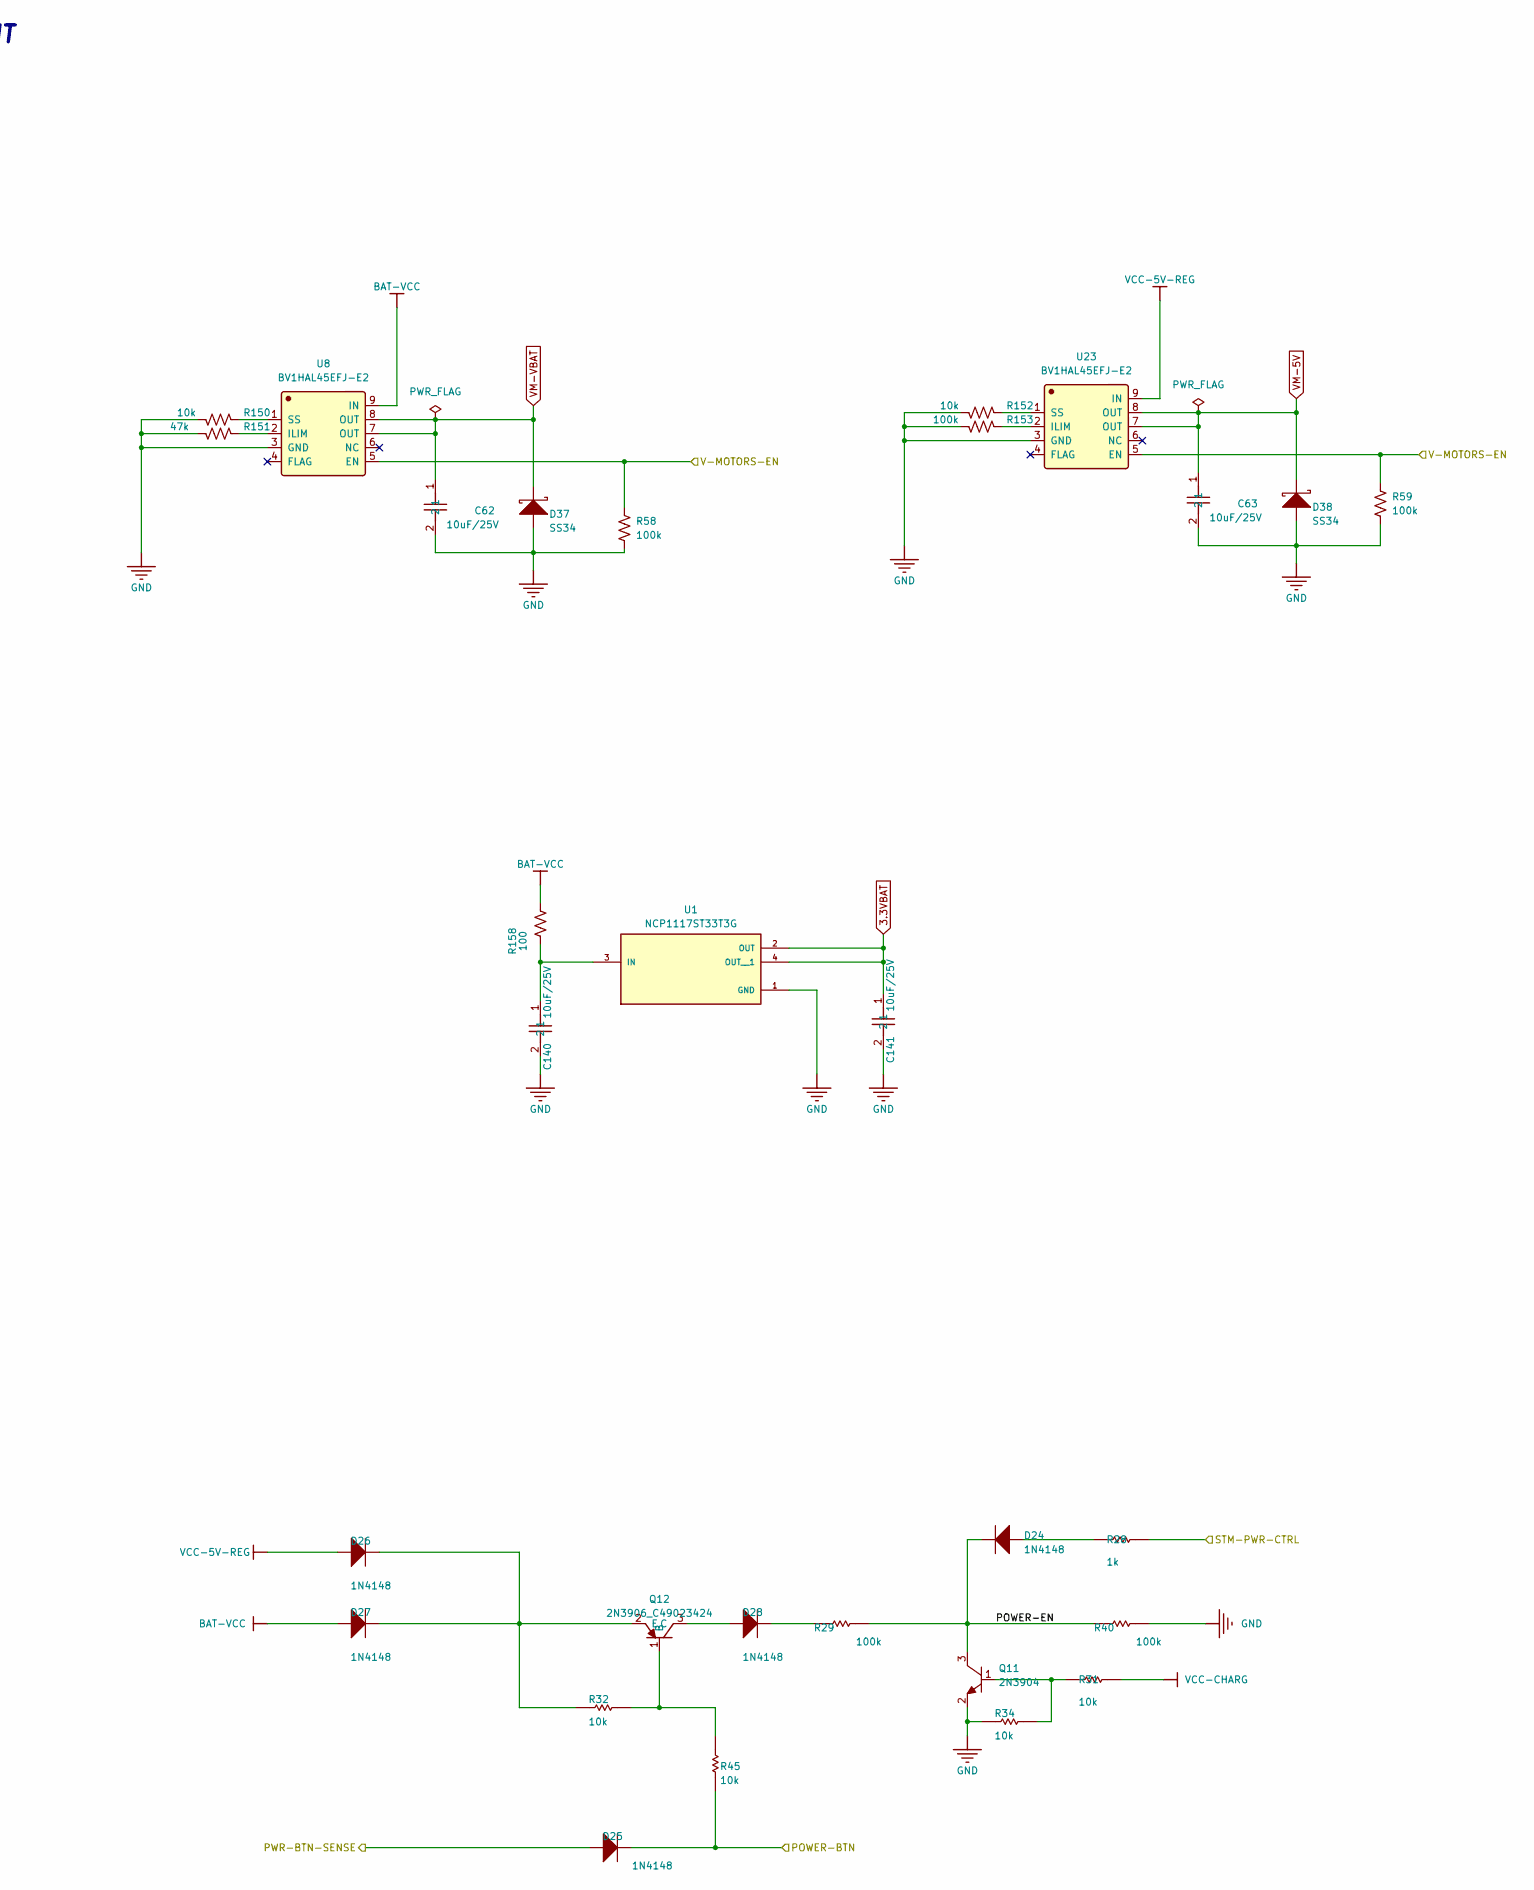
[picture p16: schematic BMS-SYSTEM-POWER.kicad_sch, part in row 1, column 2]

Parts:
C62, C63, C95, C104, C106, C113, C114, C115, C116, C121, C122, C124, C131, C132, C140, C141, C144, C145, C146, C147: 10uF/25V; C_0603_1608Metric; LCSC C96446
C102, C107, C111, C117, C118, C119, C127, C128, C129: 100nF/50V; C_0603_1608Metric; Manufacturer_Part_Number CL10B104KB8NNNC; LCSC C1591
C112, C120, C130: 1.2nF/50V; C_0603_1608Metric; Manufacturer_Part_Number CL10B104KB8NNNC; LCSC C1590
D23: 3V3-STM; LED0603-B; VOLTAGERATE *; MANUFACTURINGPARTNUMBER *; LCSC C19171394
D24, D25, D26, D27, D28: 1N4148; SOD123; VOLTAGERATE *; MANUFACTURINGPARTNUMBER *; LCSC C917030
D37, D38: SS34; D_SMA; VOLTAGERATE *; MANUFACTURINGPARTNUMBER *; LCSC C22448055
L2, L3, L4: CYA0630-3_3UH; Manufacturer Part CYA0630-3.3UH; LCSC C5189747
Q11: 2N3904; SOT23-3D; VOLTAGERATE *; MANUFACTURINGPARTNUMBER *; LCSC C50176433
Q12: 2N3906_C49023424; Manufacturer Part 2N3906; LCSC C49023424
R10, R16, R58, R59, R153: 100k; R_0603_1608Metric
R14, R28: 1k; R_0603_1608Metric; VOLTAGERATE *; MANUFACTURINGPARTNUMBER *
R23, R150, R152: 10k; R_0603_1608Metric
R29, R40: 100k; R_0603_1608Metric; VOLTAGERATE *; MANUFACTURINGPARTNUMBER *
R31, R32, R34, R45: 10k; R_0603_1608Metric; VOLTAGERATE *; MANUFACTURINGPARTNUMBER *
R141, R146, R154: 10; R_0603_1608Metric
R143, R148, R155: 12k; R_0603_1608Metric
R144, R156: 69.8k; R_0603_1608Metric
R145, R157: 22.1k; R_0603_1608Metric
R147: 20k; R_0603_1608Metric
R149: 2.2k; R_0603_1608Metric
R151: 47k; R_0603_1608Metric
R158: 100; R_0805_2012Metric
U1: NCP1117ST33T3G; SOT230P700X180-4N; LCSC C26537
U8, U23: BV1HAL45EFJ-E2; Manufacturer Part BV1HAL45EFJ-E2; LCSC C3229246
U21, U22, U24: AP64501SP-13; Manufacturer Part AP64501SP-13; LCSC C2071517

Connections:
3.3VBAT: C141.1, U1.2 (OUT), U1.4 (OUT__1); also elsewhere on the board
+3.3VP: R16.1, R23.1, U21.3 (EN); also elsewhere on the board
/BUTTON-LED/POWER-BTN: D25.2 (K), R45.1; also elsewhere on the board
/CM5-HIGHSPEED/PCIE_PWR_EN: R10.1, R23.2, U24.3 (EN); also elsewhere on the board
/MCU-STM32/PWR-BTN-SENSE: D25.1 (A); also elsewhere on the board
/MCU-STM32/STM-PWR-CTRL: R28.2; also elsewhere on the board
/MCU-STM32/~STM32_RST: R58.1, R59.1, U8.5 (EN), U23.5 (EN); also elsewhere on the board
/POWER/POWER-EN: D24.2 (K), Q11.3 (C), R29.2, R40.1, U22.3 (EN)
BAT-VCC: C95.1, C102.1, C104.1, C106.1, C115.1, C116.1, C117.1, C124.1, C127.1, D27.1 (A), R158.2, U8.9 (IN), U21.2 (VIN), U22.2 (VIN), U24.2 (VIN); also elsewhere on the board
GND: C62.2, C63.2, C95.2, C102.2, C104.2, C106.2, C107.2, C112.2, C113.2, C114.2, C115.2, C116.2, C117.2, C118.2, C120.2, C121.2, C122.2, C124.2, C127.2, C128.2, C130.2, C131.2, C132.2, C140.2, C141.2, C144.2, C145.2, C146.2, C147.2, D37.1 (A), D38.1 (A), Q11.2 (E), R10.2, R14.1, R16.2, R34.2, R40.2, R58.2, R59.2, R145.1, R149.1, R150.1, R151.1, R152.1, R153.1, R157.1, U1.1 (GND), U8.3 (GND), U21.7 (GND), U21.9 (EP), U22.7 (GND), U22.9 (EP), U23.3 (GND), U24.7 (GND), U24.9 (EP); also elsewhere on the board
unnamed: C111.1, R141.1
unnamed: C112.1, R143.1
unnamed: C119.1, R146.1
unnamed: C120.1, R147.1
unnamed: C129.1, R154.1
unnamed: C130.1, R155.1
unnamed: D23.2, R14.2
unnamed: D24.1 (A), R28.1
unnamed: D26.2 (K), D27.2 (K), Q12.2 (E), R32.2
unnamed: D28.1 (A), Q12.3 (C)
unnamed: D28.2 (K), R29.1
unnamed: Q11.1 (B), R31.1, R34.1
unnamed: Q12.1 (B), R32.1, R45.2
unnamed: C140.1, R158.1, U1.3 (IN)
unnamed: R151.2, U8.2 (ILIM)
unnamed: R150.2, U8.1 (SS)
unnamed: C111.2, U21.1 (BST)
unnamed: R143.2, U21.6 (COMP)
unnamed: R144.1, R145.2, U21.5 (FB)
unnamed: C107.1, U21.4 (SS)
unnamed: L2.1, R141.2, U21.8 (SW)
unnamed: C119.2, U22.1 (BST)
unnamed: R147.2, U22.6 (COMP)
unnamed: R148.1, R149.2, U22.5 (FB)
unnamed: C118.1, U22.4 (SS)
unnamed: L3.1, R146.2, U22.8 (SW)
unnamed: R153.2, U23.2 (ILIM)
unnamed: R152.2, U23.1 (SS)
unnamed: C129.2, U24.1 (BST)
unnamed: R155.2, U24.6 (COMP)
unnamed: R156.1, R157.2, U24.5 (FB)
unnamed: C128.1, U24.4 (SS)
unnamed: L4.1, R154.2, U24.8 (SW)
VCC3V3_M2: C131.1, C132.1, C144.1, C145.1, L4.2, R156.2; also elsewhere on the board
VCC-3V3-P: C113.1, C114.1, C146.1, D23.1, L2.2, R144.2; also elsewhere on the board
VCC-5V-REG: C121.1, C122.1, C147.1, D26.1 (A), L3.2, R148.2, U23.9 (IN); also elsewhere on the board
VCC-CHARG: R31.2; also elsewhere on the board
VM-5V: C63.1, D38.2 (K), U23.7 (OUT), U23.8 (OUT); also elsewhere on the board
VM-VBAT: C62.1, D37.2 (K), U8.7 (OUT), U8.8 (OUT); also elsewhere on the board

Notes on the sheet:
POWER MANAGMENT
STM-PWR-CTRL need to use for both EN and OFF from STM32 GPIO pin. 1- Hold EN to HIGH after buttone pressed 2- OFF board

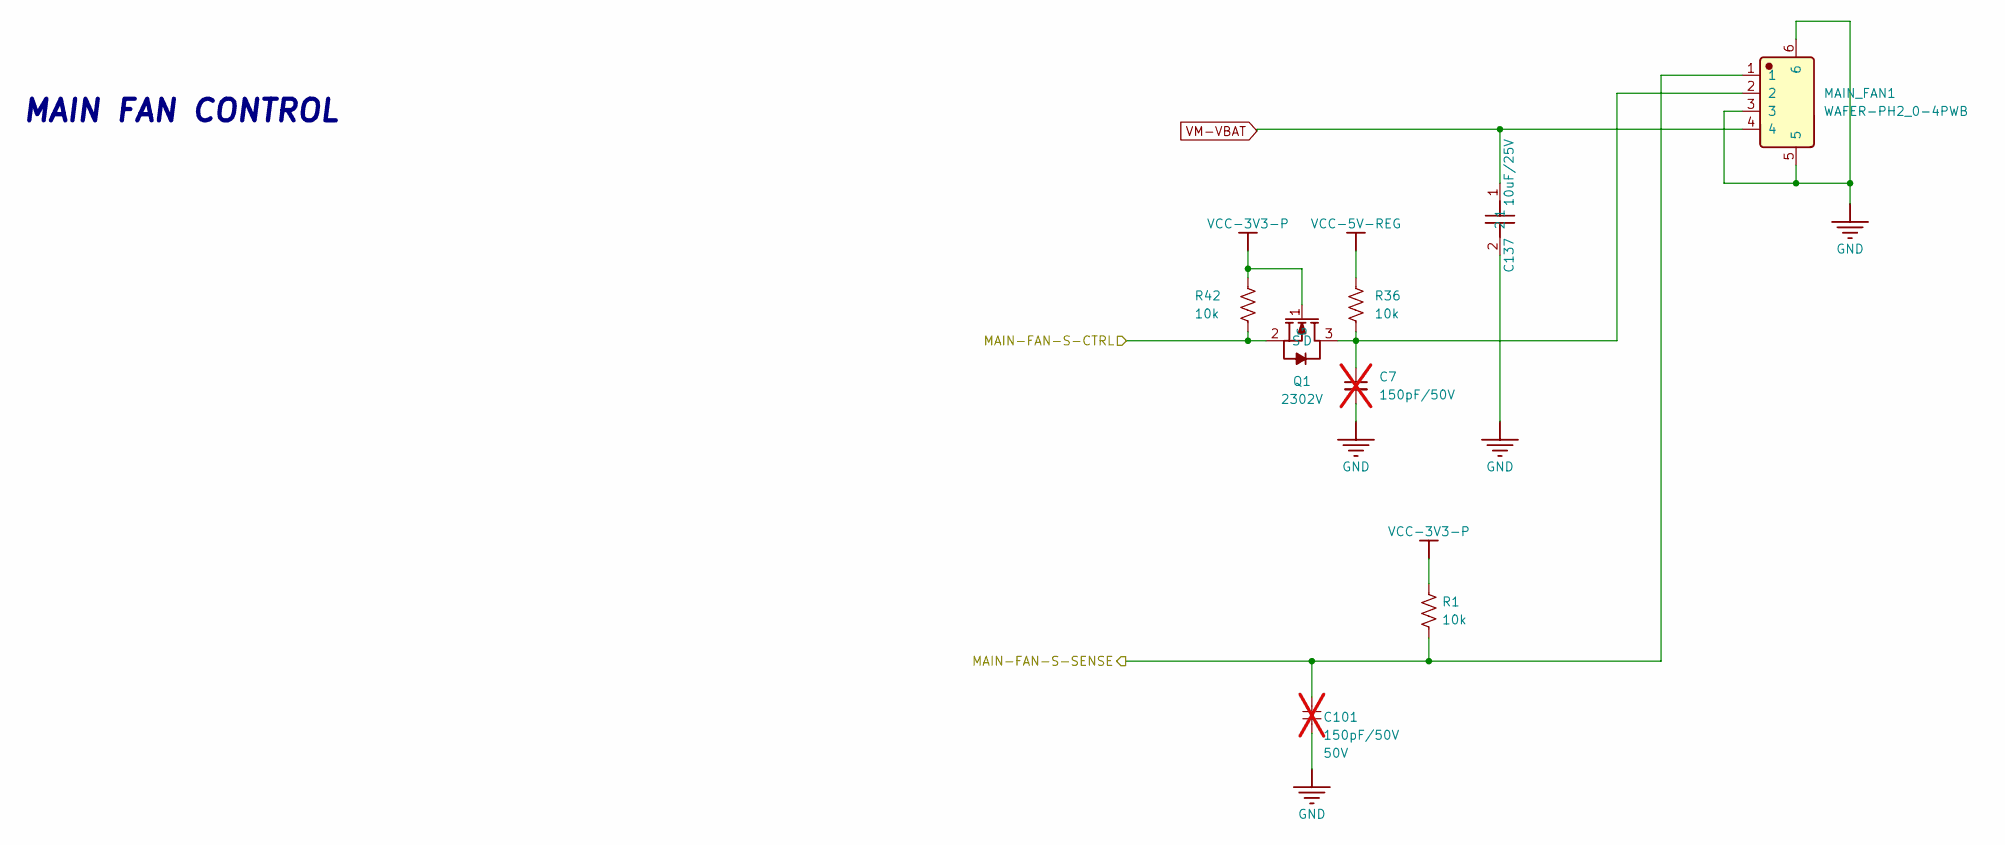
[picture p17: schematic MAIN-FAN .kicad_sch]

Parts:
C7: 150pF/50V; C_0603_1608Metric; not fitted
C101: 150pF/50V; C_0603_1608Metric; VOLTAGERATE 50V; MANUFACTURINGPARTNUMBER *; not fitted
C137: 10uF/25V; C_0603_1608Metric; LCSC C96446
MAIN_FAN1: WAFER-PH2_0-4PWB; Manufacturer Part WAFER-PH2.0-4PWB; LCSC C3029442
Q1: 2302V; Manufacturer Part 2302V; LCSC C7431443
R1, R36, R42: 10k; R_0603_1608Metric

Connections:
/MAIN-FAN/MAIN-FAN-S-CTRL: Q1.2 (S), R42.2; also elsewhere on the board
/MAIN-FAN/MAIN-FAN-S-SENSE: C101.1, MAIN_FAN1.1, R1.2; also elsewhere on the board
GND: C7.2, C101.2, C137.2, MAIN_FAN1.3, MAIN_FAN1.5, MAIN_FAN1.6; also elsewhere on the board
unnamed: C7.1, MAIN_FAN1.2, Q1.3 (D), R36.2
VCC-3V3-P: Q1.1 (G), R1.1, R42.1; also elsewhere on the board
VCC-5V-REG: R36.1; also elsewhere on the board
VM-VBAT: C137.1, MAIN_FAN1.4; also elsewhere on the board

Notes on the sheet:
MAIN FAN CONTROL

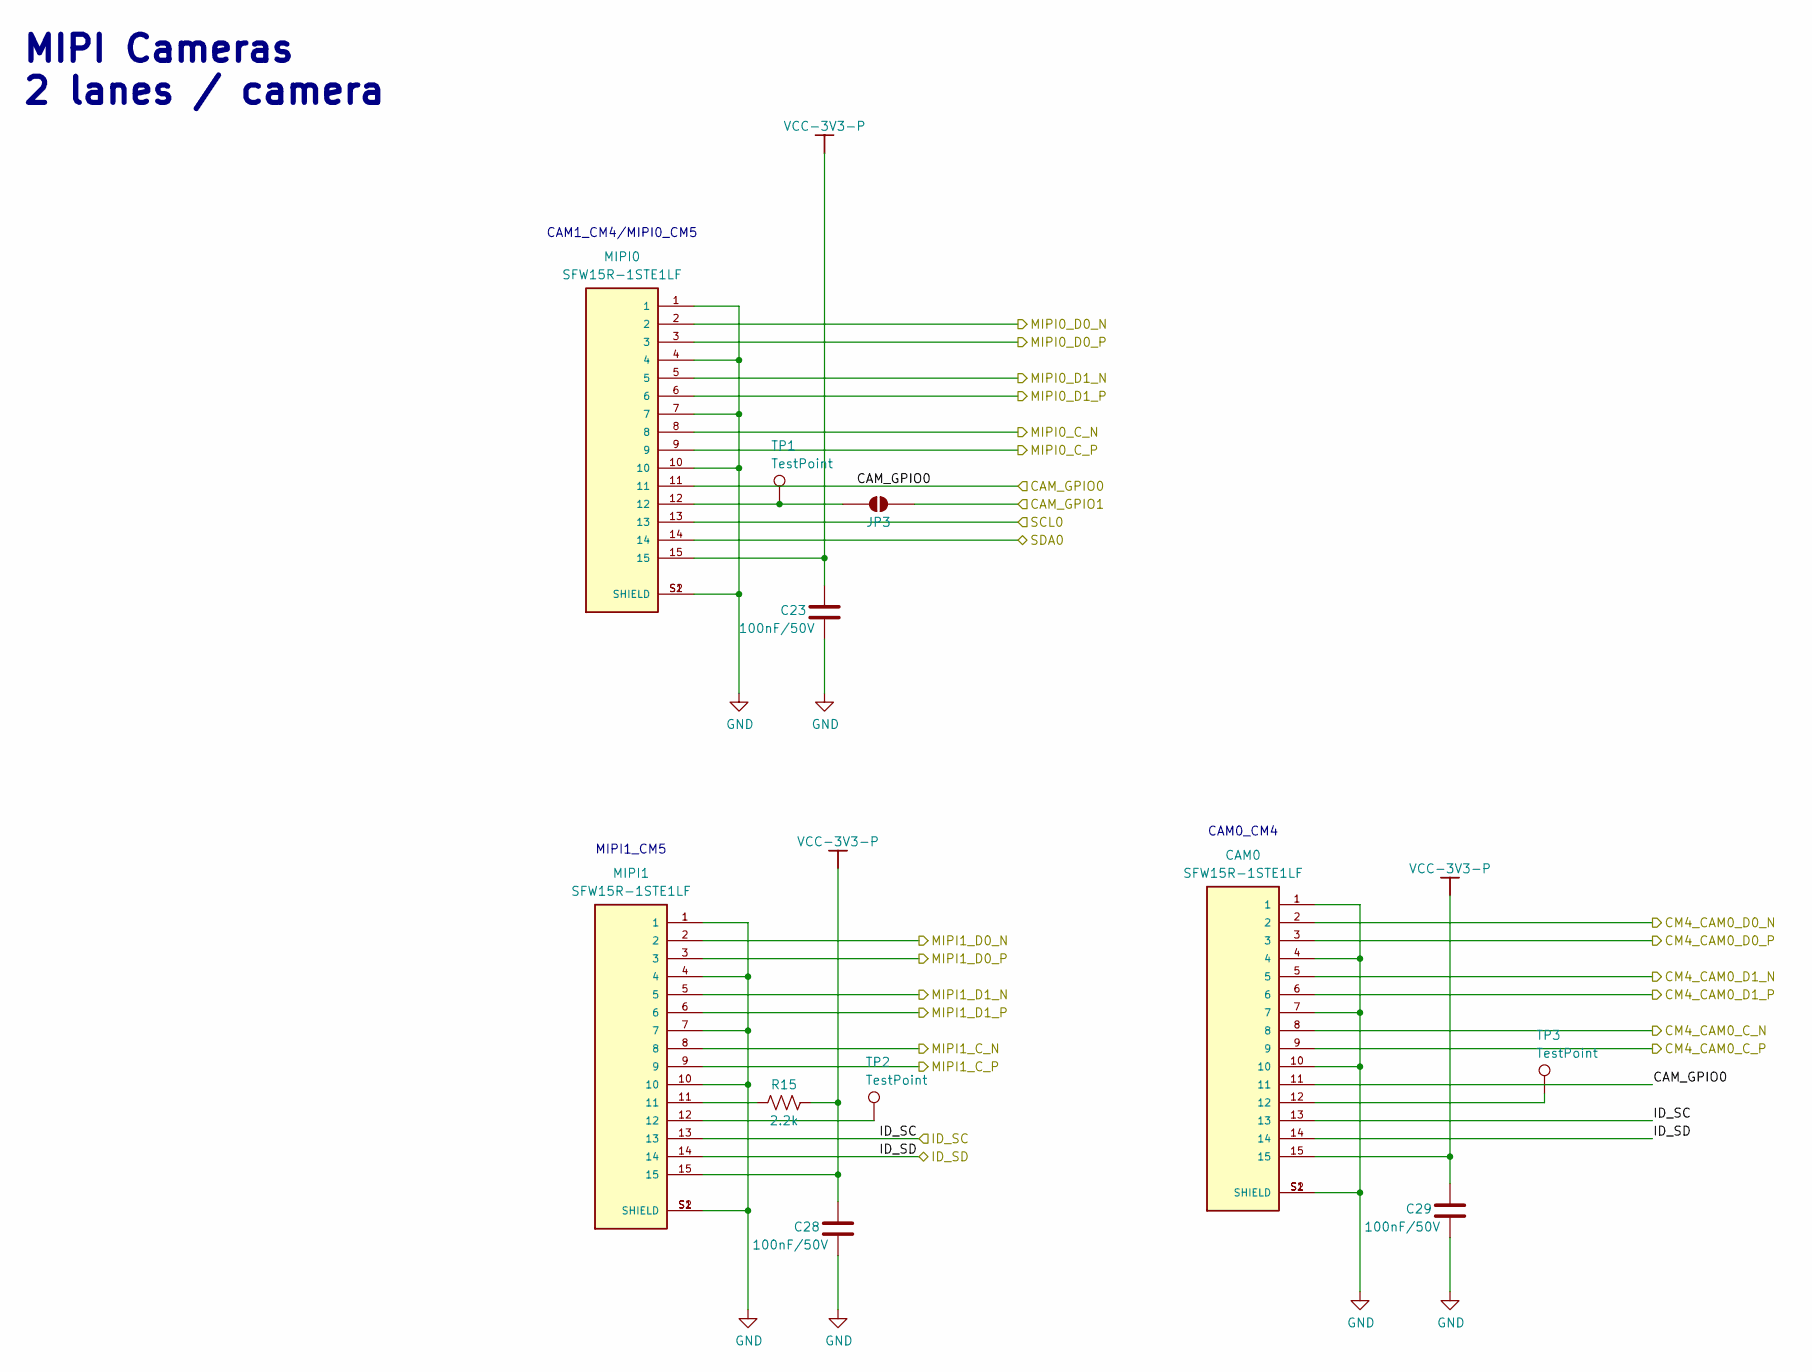
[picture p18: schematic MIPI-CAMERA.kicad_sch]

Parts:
C23, C28, C29: 100nF/50V; C_0603_1608Metric; LCSC C1591
CAM0: SFW15R-1STE1LF; AMPHENOL_SFW15R-1STE1LF; PARTREV AC; LCSC C3168538
JP3: SolderJumper-2_P1.3mm_Open_RoundedPad1.0x1.5mm
MIPI0, MIPI1: SFW15R-1STE1LF; AMPHENOL_SFW15R-1STE1LF; PARTREV AC; LCSC C3168538
R15: 2.2k; R_0603_1608Metric
TP1, TP2, TP3: TestPoint; TestPoint_Pad_D2.0mm

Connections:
/CAMERA/CAM_GPIO0: CAM0.11, MIPI0.11; also elsewhere on the board
/CAMERA/CAM_GPIO1: JP3.2 (B); also elsewhere on the board
/CAMERA/CM4_CAM0_C_N: CAM0.8; also elsewhere on the board
/CAMERA/CM4_CAM0_C_P: CAM0.9; also elsewhere on the board
/CAMERA/CM4_CAM0_D0_N: CAM0.2; also elsewhere on the board
/CAMERA/CM4_CAM0_D0_P: CAM0.3; also elsewhere on the board
/CAMERA/CM4_CAM0_D1_N: CAM0.5; also elsewhere on the board
/CAMERA/CM4_CAM0_D1_P: CAM0.6; also elsewhere on the board
/CAMERA/ID_SC: CAM0.13, MIPI1.13; also elsewhere on the board
/CAMERA/ID_SD: CAM0.14, MIPI1.14; also elsewhere on the board
/CAMERA/MIPI0_C_N: MIPI0.8; also elsewhere on the board
/CAMERA/MIPI0_C_P: MIPI0.9; also elsewhere on the board
/CAMERA/MIPI0_D0_N: MIPI0.2; also elsewhere on the board
/CAMERA/MIPI0_D0_P: MIPI0.3; also elsewhere on the board
/CAMERA/MIPI0_D1_N: MIPI0.5; also elsewhere on the board
/CAMERA/MIPI0_D1_P: MIPI0.6; also elsewhere on the board
/CAMERA/MIPI1_C_N: MIPI1.8; also elsewhere on the board
/CAMERA/MIPI1_C_P: MIPI1.9; also elsewhere on the board
/CAMERA/MIPI1_D0_N: MIPI1.2; also elsewhere on the board
/CAMERA/MIPI1_D0_P: MIPI1.3; also elsewhere on the board
/CAMERA/MIPI1_D1_N: MIPI1.5; also elsewhere on the board
/CAMERA/MIPI1_D1_P: MIPI1.6; also elsewhere on the board
/CAMERA/SCL0: MIPI0.13; also elsewhere on the board
/CAMERA/SDA0: MIPI0.14; also elsewhere on the board
GND: C23.2, C28.2, C29.2, CAM0.1, CAM0.4, CAM0.7, CAM0.10, CAM0.S1 (SHIELD), CAM0.S2 (SHIELD), MIPI0.1, MIPI0.4, MIPI0.7, MIPI0.10, MIPI0.S1 (SHIELD), MIPI0.S2 (SHIELD), MIPI1.1, MIPI1.4, MIPI1.7, MIPI1.10, MIPI1.S1 (SHIELD), MIPI1.S2 (SHIELD); also elsewhere on the board
unnamed: CAM0.12, TP3.1 (1_1)
unnamed: JP3.1 (A), MIPI0.12, TP1.1 (1_1)
unnamed: MIPI1.11, R15.1
unnamed: MIPI1.12, TP2.1 (1_1)
VCC-3V3-P: C23.1, C28.1, C29.1, CAM0.15, MIPI0.15, MIPI1.15, R15.2; also elsewhere on the board

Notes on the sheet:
CAM1_CM4/MIPI0_CM5
CAM0_CM4
MIPI1_CM5
MIPI Cameras 2 lanes / camera

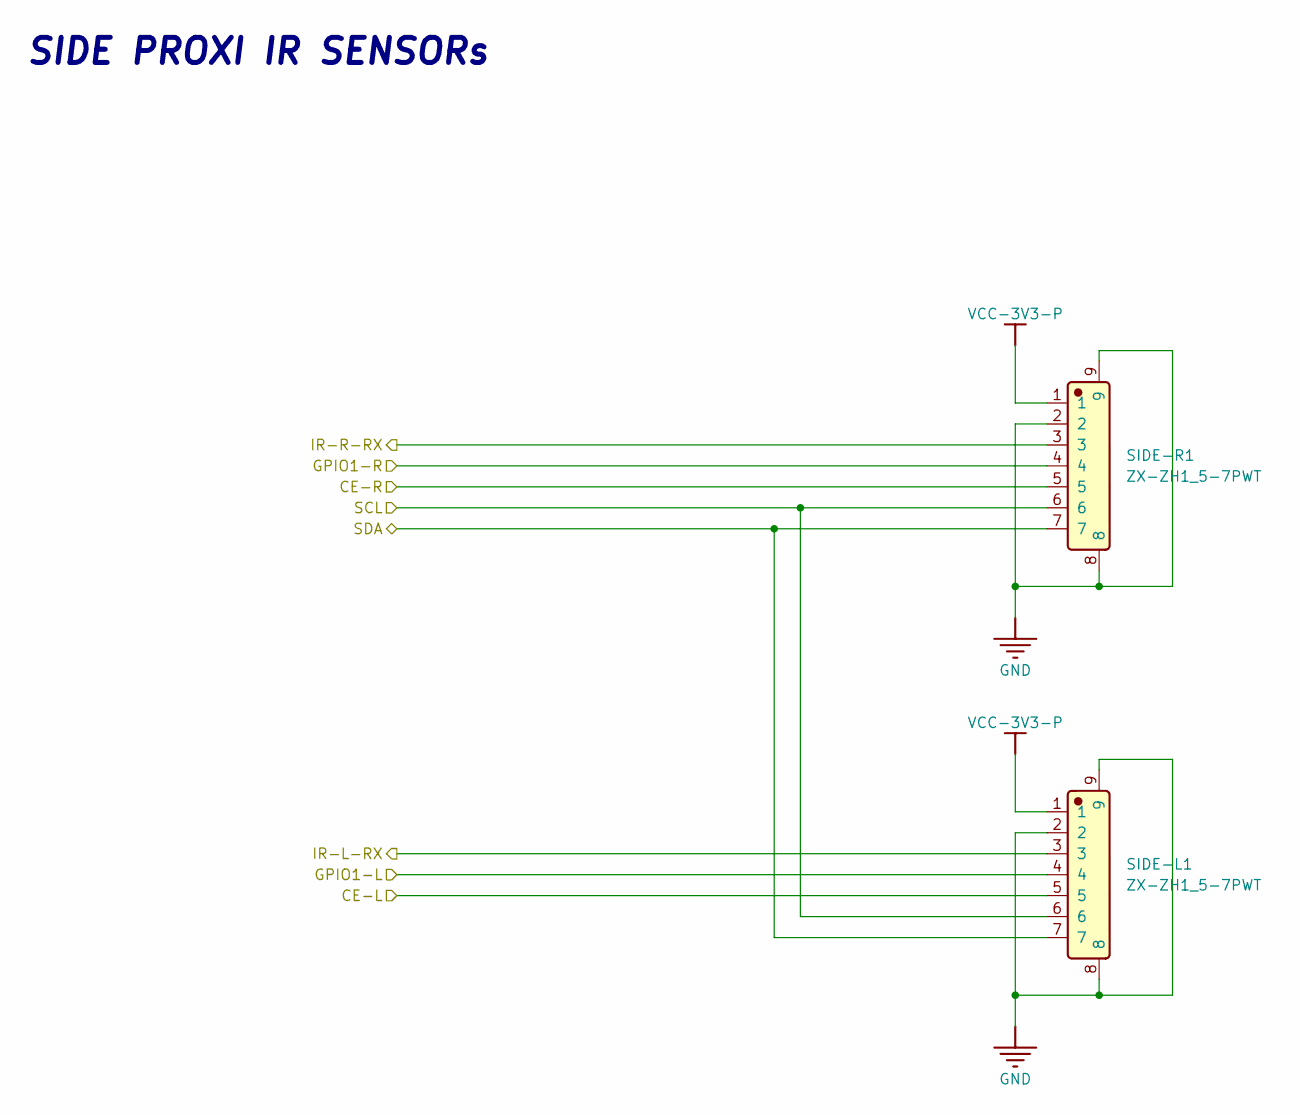
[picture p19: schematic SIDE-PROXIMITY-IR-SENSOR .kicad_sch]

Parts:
SIDE-L1: ZX-ZH1_5-7PWT; Manufacturer Part ZX-ZH1.5-7PWT; LCSC C19272410
SIDE-R1: ZX-ZH1_5-7PWT; Manufacturer Part ZX-ZH1.5-7PWT; LCSC C19272410

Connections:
/MCU-STM32/I2C4_SCL: SIDE-L1.6, SIDE-R1.6; also elsewhere on the board
/MCU-STM32/I2C4_SDA: SIDE-L1.7, SIDE-R1.7; also elsewhere on the board
/MCU-STM32/SIDE-PROXI-CE-L: SIDE-L1.5; also elsewhere on the board
/MCU-STM32/SIDE-PROXI-CE-R: SIDE-R1.5; also elsewhere on the board
/MCU-STM32/SIDE-PROXI-GPIO-L: SIDE-L1.4; also elsewhere on the board
/MCU-STM32/SIDE-PROXI-GPIO-R: SIDE-R1.4; also elsewhere on the board
/MCU-STM32/USART2-IR-L-RX: SIDE-R1.3; also elsewhere on the board
/MCU-STM32/USART4-IR-R-RX: SIDE-L1.3; also elsewhere on the board
GND: SIDE-L1.2, SIDE-L1.8, SIDE-L1.9, SIDE-R1.2, SIDE-R1.8, SIDE-R1.9; also elsewhere on the board
VCC-3V3-P: SIDE-L1.1, SIDE-R1.1; also elsewhere on the board

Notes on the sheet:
SIDE PROXI IR SENSORs

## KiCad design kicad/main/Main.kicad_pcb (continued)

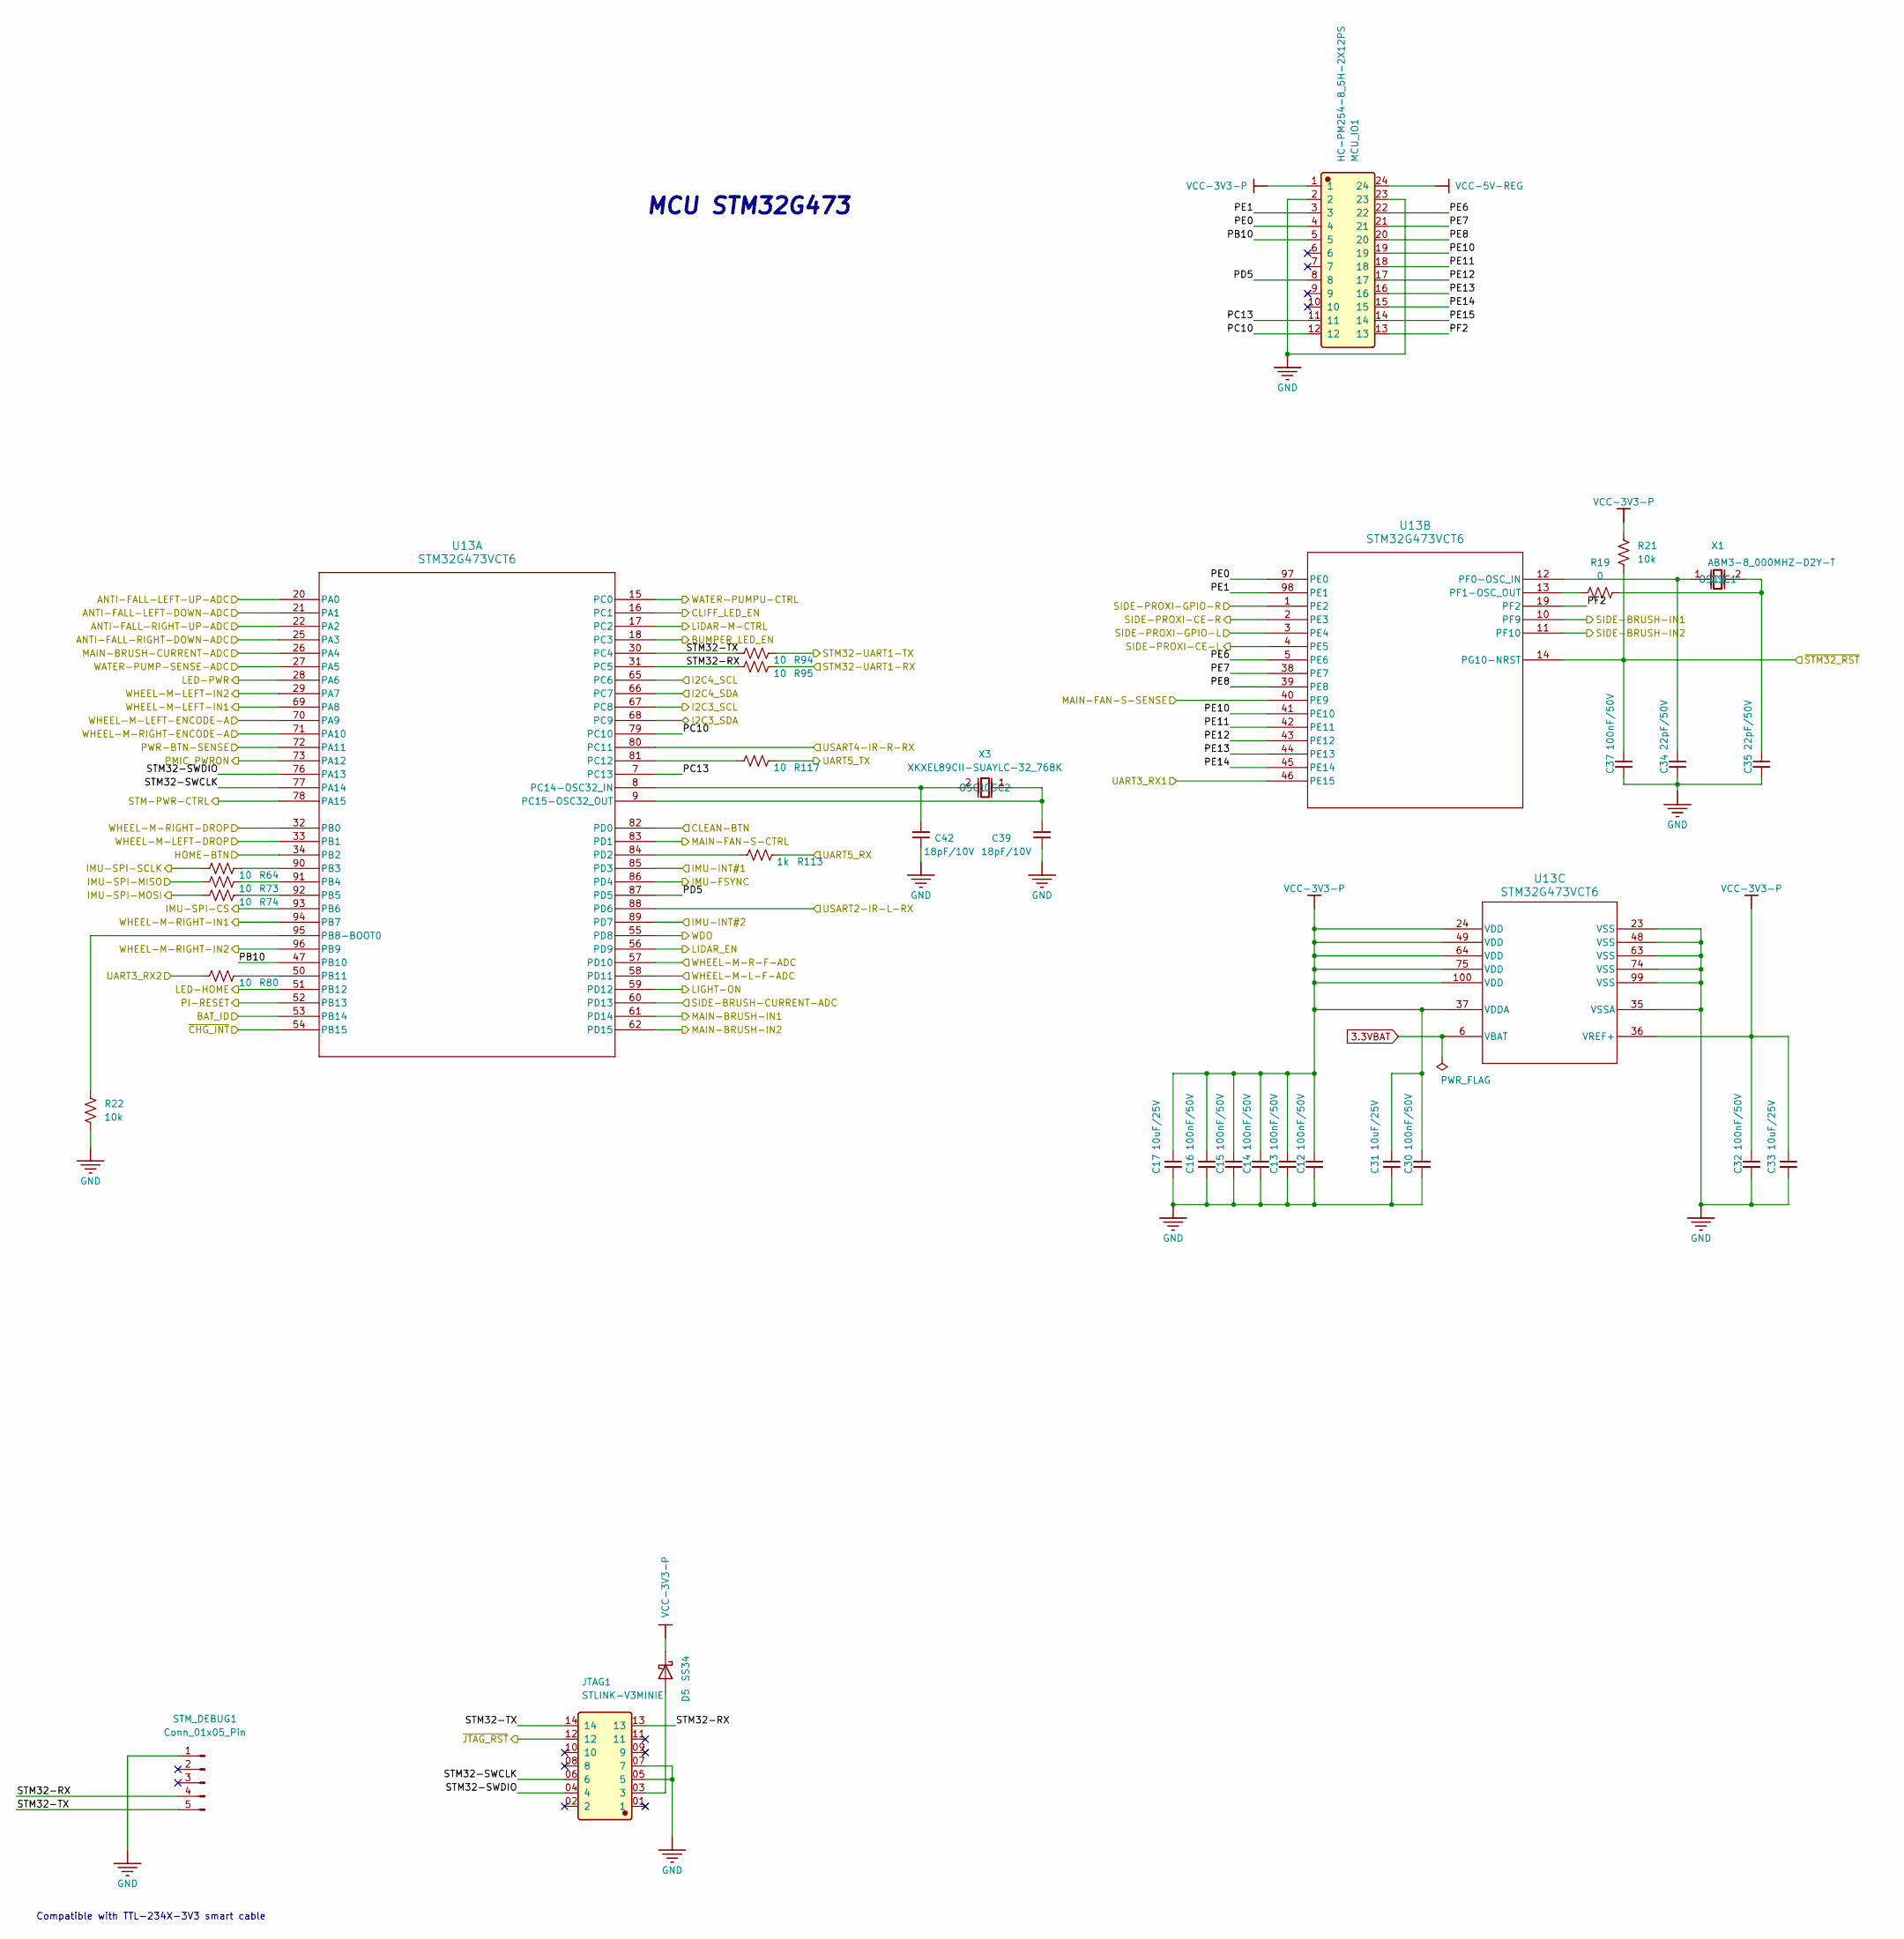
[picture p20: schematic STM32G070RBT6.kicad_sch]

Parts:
C12, C13, C14, C15, C16, C30, C32, C37: 100nF/50V; C_0603_1608Metric; LCSC C1591
C17, C31, C33: 10uF/25V; C_0603_1608Metric; LCSC C96446
C34, C35: 22pF/50V; C_0603_1608Metric
C39, C42: 18pF/10V; C_0603_1608Metric
D5: SS34; D_SMA; LCSC C22448055
JTAG1: STLINK-V3MINIE; FTSH-107-01-L-DV-K-A; Manufacturer Part FTSH-107-01-L-DV-K-A; LCSC C5563894
MCU_IO1: HC-PM254-8_5H-2X12PS; Manufacturer Part HC-PM254-8.5H-2x12PS; LCSC C22436159
R19: 0; R_0603_1608Metric
R21, R22: 10k; R_0603_1608Metric
R64, R73, R74, R80, R94, R95, R117: 10; R_0603_1608Metric
R113: 1k; R_0603_1608Metric
STM_DEBUG1: Conn_01x05_Pin; PinHeader_1x05_P2.54mm_Vertical; LCSC C42431835
U13: STM32G473VCT6; LQFP100-14x14mm; LCSC C730121
X1: ABM3-8_000MHZ-D2Y-T; Manufacturer Part ABM3-8.000MHZ-D2Y-T; LCSC C144380
X3: XKXEL89CII-SUAYLC-32_768K; Manufacturer Part XKXEL89CII-SUAYLC-32.768K; LCSC C18214309

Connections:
3.3VBAT: U13.6 (VBAT); also elsewhere on the board
/ANTI-FALL/ANTI-FALL-LEFT-DOWN-ADC: U13.21 (PA1); also elsewhere on the board
/ANTI-FALL/ANTI-FALL-LEFT-UP-ADC: U13.20 (PA0); also elsewhere on the board
/ANTI-FALL/ANTI-FALL-RIGHT-DOWN-ADC: U13.25 (PA3); also elsewhere on the board
/ANTI-FALL/ANTI-FALL-RIGHT-UP-ADC: U13.22 (PA2); also elsewhere on the board
/ANTI-FALL/BUMPER_LED_EN: U13.18 (PC3); also elsewhere on the board
/ANTI-FALL/CLIFF_LED_EN: U13.16 (PC1); also elsewhere on the board
/BATTERY-CHARGER/ID: U13.53 (PB14); also elsewhere on the board
/BATTERY-CHARGER/SCL: U13.67 (PC8); also elsewhere on the board
/BATTERY-CHARGER/SDA: U13.68 (PC9); also elsewhere on the board
/BATTERY-CHARGER/~INT: U13.54 (PB15); also elsewhere on the board
/BUTTON-LED/CLEAN-BTN: U13.82 (PD0); also elsewhere on the board
/BUTTON-LED/HOME-BTN: U13.34 (PB2); also elsewhere on the board
/BUTTON-LED/LED-HOME: U13.51 (PB12); also elsewhere on the board
/BUTTON-LED/LED-PWR: U13.28 (PA6); also elsewhere on the board
/CM5-GPIO/PMIC_EN: U13.52 (PB13); also elsewhere on the board
/CM5-GPIO/RUN_PG: U13.73 (PA12); also elsewhere on the board
/CM5-GPIO/UART2_RX: R94.2; also elsewhere on the board
/CM5-GPIO/UART2_TX: R95.2; also elsewhere on the board
/FRONT SENSORS/IR-F-RX1: U13.46 (PE15); also elsewhere on the board
/FRONT SENSORS/IR-F-RX2: R80.1; also elsewhere on the board
/FRONT SENSORS/LIGHT-ON: U13.59 (PD12); also elsewhere on the board
/IMU-CS: U13.93 (PB6); also elsewhere on the board
/IMU-FSYNC: U13.86 (PD4); also elsewhere on the board
/IMU-INT1: U13.85 (PD3); also elsewhere on the board
/IMU-INT2: U13.89 (PD7); also elsewhere on the board
/IMU-MISO: R73.1; also elsewhere on the board
/IMU-MOSI: R74.1; also elsewhere on the board
/IMU-SCLK: R64.1; also elsewhere on the board
/LiDAR/LIDAR_EN: U13.56 (PD9); also elsewhere on the board
/LiDAR/LiDAR-MOTOR-CTRL: U13.17 (PC2); also elsewhere on the board
/LiDAR/LiDAR-RXD: R113.2; also elsewhere on the board
/LiDAR/LiDAR-TXD: R117.2; also elsewhere on the board
/MAIN-BRUSH MOTOR/MAIN-BRUSH-CURRENT-ADC: U13.26 (PA4); also elsewhere on the board
/MAIN-BRUSH MOTOR/MAIN-BRUSH-IN1: U13.61 (PD14); also elsewhere on the board
/MAIN-BRUSH MOTOR/MAIN-BRUSH-IN2: U13.62 (PD15); also elsewhere on the board
/MAIN-FAN/MAIN-FAN-S-CTRL: U13.83 (PD1); also elsewhere on the board
/MAIN-FAN/MAIN-FAN-S-SENSE: U13.40 (PE9); also elsewhere on the board
/MCU-STM32/I2C4_SCL: U13.65 (PC6); also elsewhere on the board
/MCU-STM32/I2C4_SDA: U13.66 (PC7); also elsewhere on the board
/MCU-STM32/PB10: MCU_IO1.5, U13.47 (PB10)
/MCU-STM32/PC10: MCU_IO1.12, U13.79 (PC10)
/MCU-STM32/PC13: MCU_IO1.11, U13.7 (PC13)
/MCU-STM32/PD5: MCU_IO1.8, U13.87 (PD5)
/MCU-STM32/PE0: MCU_IO1.4, U13.97 (PE0)
/MCU-STM32/PE1: MCU_IO1.3, U13.98 (PE1)
/MCU-STM32/PE6: MCU_IO1.22, U13.5 (PE6)
/MCU-STM32/PE7: MCU_IO1.21, U13.38 (PE7)
/MCU-STM32/PE8: MCU_IO1.20, U13.39 (PE8)
/MCU-STM32/PE10: MCU_IO1.19, U13.41 (PE10)
/MCU-STM32/PE11: MCU_IO1.18, U13.42 (PE11)
/MCU-STM32/PE12: MCU_IO1.17, U13.43 (PE12)
/MCU-STM32/PE13: MCU_IO1.16, U13.44 (PE13)
/MCU-STM32/PE14: MCU_IO1.15, U13.45 (PE14)
/MCU-STM32/PE15: MCU_IO1.14
/MCU-STM32/PF2: MCU_IO1.13, U13.19 (PF2)
/MCU-STM32/PWR-BTN-SENSE: U13.72 (PA11); also elsewhere on the board
/MCU-STM32/SIDE-BRUSH-CURRENT-ADC: U13.60 (PD13); also elsewhere on the board
/MCU-STM32/SIDE-BRUSH-IN1: U13.10 (PF9); also elsewhere on the board
/MCU-STM32/SIDE-BRUSH-IN2: U13.11 (PF10); also elsewhere on the board
/MCU-STM32/SIDE-PROXI-CE-L: U13.4 (PE5); also elsewhere on the board
/MCU-STM32/SIDE-PROXI-CE-R: U13.2 (PE3); also elsewhere on the board
/MCU-STM32/SIDE-PROXI-GPIO-L: U13.3 (PE4); also elsewhere on the board
/MCU-STM32/SIDE-PROXI-GPIO-R: U13.1 (PE2); also elsewhere on the board
/MCU-STM32/STM32-RX: JTAG1.13, R95.1, STM_DEBUG1.4, U13.31 (PC5)
/MCU-STM32/STM32-SWCLK: JTAG1.06 (6), U13.77 (PA14)
/MCU-STM32/STM32-SWDIO: JTAG1.04 (4), U13.76 (PA13)
/MCU-STM32/STM32-TX: JTAG1.14, R94.1, STM_DEBUG1.5, U13.30 (PC4)
/MCU-STM32/STM-PWR-CTRL: U13.78 (PA15); also elsewhere on the board
/MCU-STM32/USART2-IR-L-RX: U13.88 (PD6); also elsewhere on the board
/MCU-STM32/USART4-IR-R-RX: U13.80 (PC11); also elsewhere on the board
/MCU-STM32/WATER-PUMP-SENSE-ADC: U13.27 (PA5); also elsewhere on the board
/MCU-STM32/WATER-PUMPU-CTRL: U13.15 (PC0); also elsewhere on the board
/MCU-STM32/WDO: U13.55 (PD8); also elsewhere on the board
/MCU-STM32/WHEEL-M-L-F-ADC: U13.58 (PD11); also elsewhere on the board
/MCU-STM32/WHEEL-M-LEFT-DROP: U13.33 (PB1); also elsewhere on the board
/MCU-STM32/WHEEL-M-LEFT-ENCODE-A: U13.70 (PA9); also elsewhere on the board
/MCU-STM32/WHEEL-M-LEFT-IN1: U13.69 (PA8); also elsewhere on the board
/MCU-STM32/WHEEL-M-LEFT-IN2: U13.29 (PA7); also elsewhere on the board
/MCU-STM32/WHEEL-M-R-F-ADC: U13.57 (PD10); also elsewhere on the board
/MCU-STM32/WHEEL-M-RIGHT-DROP: U13.32 (PB0); also elsewhere on the board
/MCU-STM32/WHEEL-M-RIGHT-ENCODE-A: U13.71 (PA10); also elsewhere on the board
/MCU-STM32/WHEEL-M-RIGHT-IN1: U13.94 (PB7); also elsewhere on the board
/MCU-STM32/WHEEL-M-RIGHT-IN2: U13.96 (PB9); also elsewhere on the board
/MCU-STM32/~JTAG_RST: JTAG1.12; also elsewhere on the board
/MCU-STM32/~STM32_RST: C37.1, R21.1, U13.14 (PG10-NRST); also elsewhere on the board
GND: C12.2, C13.2, C14.2, C15.2, C16.2, C17.2, C30.2, C31.2, C32.2, C33.2, C34.2, C35.2, C37.2, C39.1, C42.1, JTAG1.05 (5), JTAG1.07 (7), MCU_IO1.2, MCU_IO1.23, R22.1, STM_DEBUG1.1, U13.23 (VSS), U13.35 (VSSA), U13.48 (VSS), U13.63 (VSS), U13.74 (VSS), U13.99 (VSS); also elsewhere on the board
unnamed: D5.2 (A), JTAG1.03 (3)
unnamed: R64.2, U13.90 (PB3)
unnamed: R73.2, U13.91 (PB4)
unnamed: R74.2, U13.92 (PB5)
unnamed: R22.2, U13.95 (PB8-BOOT0)
unnamed: R80.2, U13.50 (PB11)
unnamed: R117.1, U13.81 (PC12)
unnamed: C42.2, U13.8 (PC14-OSC32_IN), X3.2 (OSC2)
unnamed: C39.2, U13.9 (PC15-OSC32_OUT), X3.1 (OSC1)
unnamed: R113.1, U13.84 (PD2)
unnamed: C34.1, U13.12 (PF0-OSC_IN), X1.1 (OSC1)
unnamed: R19.1, U13.13 (PF1-OSC_OUT)
unnamed: C35.1, R19.2, X1.2 (OSC2)
VCC-3V3-P: C12.1, C13.1, C14.1, C15.1, C16.1, C17.1, C30.1, C31.1, C32.1, C33.1, D5.1 (K), MCU_IO1.1, R21.2, U13.24 (VDD), U13.36 (VREF+), U13.37 (VDDA), U13.49 (VDD), U13.64 (VDD), U13.75 (VDD), U13.100 (VDD); also elsewhere on the board
VCC-5V-REG: MCU_IO1.24; also elsewhere on the board

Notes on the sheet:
Compatible with TTL-234X-3V3 smart cable
MCU STM32G473

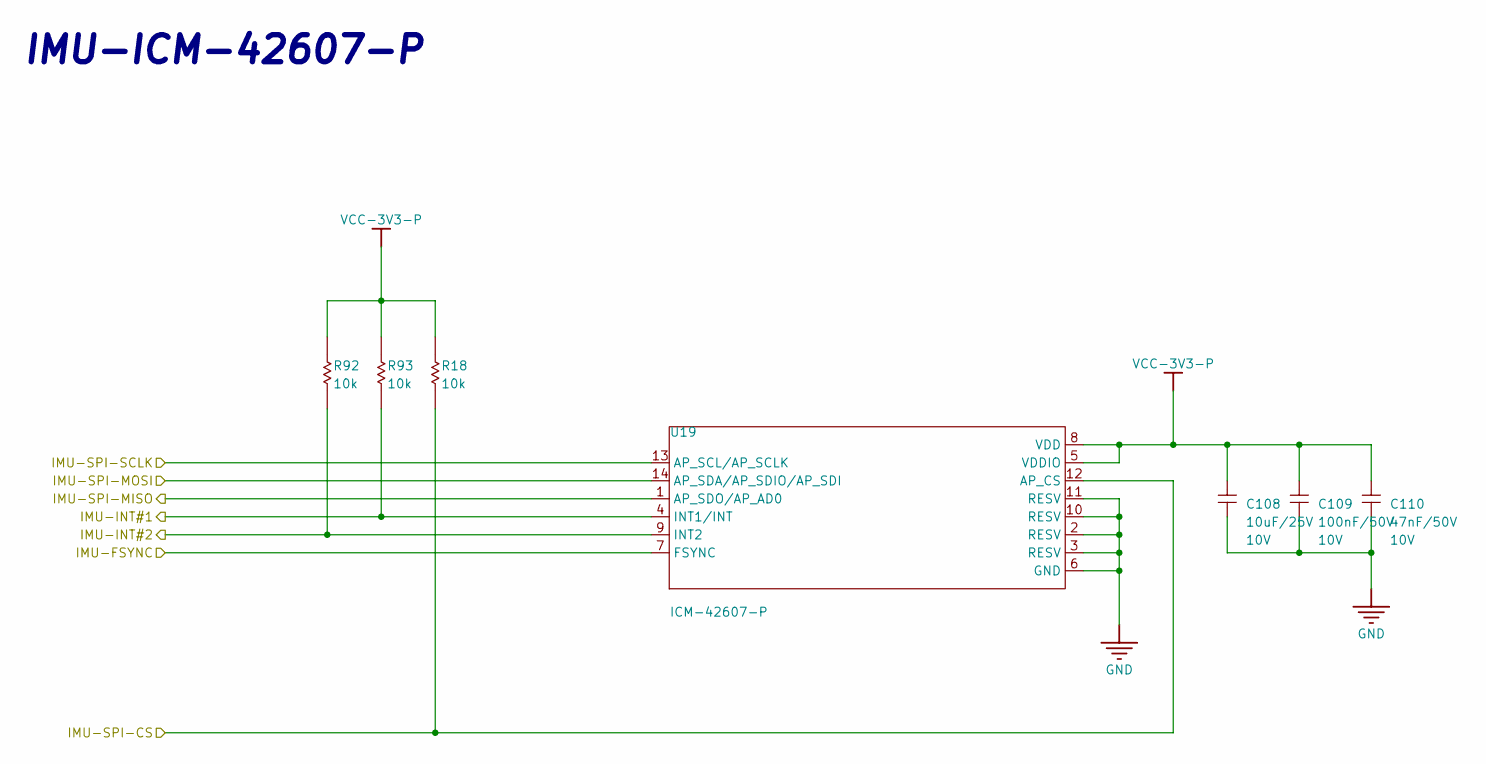
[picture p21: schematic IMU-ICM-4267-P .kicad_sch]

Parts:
C108: 10uF/25V; C_0603_1608Metric; VOLTAGERATE 10V; MANUFACTURINGPARTNUMBER *; LCSC C96446
C109: 100nF/50V; C_0603_1608Metric; VOLTAGERATE 10V; MANUFACTURINGPARTNUMBER *; LCSC C1591
C110: 47nF/50V; C_0603_1608Metric; VOLTAGERATE 10V; MANUFACTURINGPARTNUMBER *
R18, R92, R93: 10k; R_0603_1608Metric; VOLTAGERATE *; MANUFACTURINGPARTNUMBER *
U19: ICM-42607-P; VOLTAGERATE *; MANUFACTURINGPARTNUMBER *; LCSC C5129967

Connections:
/IMU-CS: R18.2, U19.12 (AP_CS); also elsewhere on the board
/IMU-FSYNC: U19.7 (FSYNC); also elsewhere on the board
/IMU-INT1: R93.2, U19.4 (INT1/INT); also elsewhere on the board
/IMU-INT2: R92.2, U19.9 (INT2); also elsewhere on the board
/IMU-MISO: U19.1 (AP_SDO/AP_AD0); also elsewhere on the board
/IMU-MOSI: U19.14 (AP_SDA/AP_SDIO/AP_SDI); also elsewhere on the board
/IMU-SCLK: U19.13 (AP_SCL/AP_SCLK); also elsewhere on the board
GND: C108.1, C109.1, C110.1, U19.2 (RESV), U19.3 (RESV), U19.6 (GND), U19.10 (RESV), U19.11 (RESV); also elsewhere on the board
VCC-3V3-P: C108.2, C109.2, C110.2, R18.1, R92.1, R93.1, U19.5 (VDDIO), U19.8 (VDD); also elsewhere on the board

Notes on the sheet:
IMU-ICM-42607-P

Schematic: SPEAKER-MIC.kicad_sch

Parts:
C5, C9, C10: 100nF/50V; C_0603_1608Metric; LCSC C1591
C11: 10uF/25V; C_0603_1608Metric; LCSC C96446
ED3: ESD5451N; ESD0402; PART REFERENCE ED7010; LCSC C5261080
ED4: ESD5451N; ESD0402; PART REFERENCE ED7011; LCSC C5261080
Q9: 2302V; Manufacturer Part 2302V; LCSC C7431443
R8, R13: 100k; R_0603_1608Metric
R9, R12: 0; R_0603_1608Metric
SPK1: ZX-ZH1_5-2PWT; Manufacturer Part ZX-ZH1.5-2PWT; LCSC C19272405
U9, U10: ICS-43434_C5656610; Manufacturer Part ICS-43434; LCSC C5656610
U11: MAX98357AETE_T; Manufacturer Part MAX98357AETE+T; LCSC C910544

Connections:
+3.3VP: R13.1; also elsewhere on the board
/CM5-GPIO/GPIO06: Q9.1 (G), R13.2; also elsewhere on the board
/CM5-GPIO/I2S_DOUT: U11.1 (DIN); also elsewhere on the board
/SPEAKER-MIC/BCLK: U9.4 (SCK), U10.4 (SCK), U11.16 (BCLK); also elsewhere on the board
/SPEAKER-MIC/DOUT: R8.1, U9.6 (SD), U10.6 (SD); also elsewhere on the board
/SPEAKER-MIC/LRCLK: U9.1 (WS), U10.1 (WS), U11.14 (LRCLK); also elsewhere on the board
GND: C5.2, C9.2, C10.2, C11.2, ED3.2, ED4.2, Q9.2 (S), R8.2, R12.1, SPK1.3, SPK1.4, U9.2 (LR), U9.3 (GND), U10.3 (GND), U11.3 (GND), U11.11 (GND), U11.15 (GND), U11.17 (EP); also elsewhere on the board
unnamed: Q9.3 (D), R9.1
unnamed: R12.2, U11.2 (GAIN_SLOT)
unnamed: ED3.1, SPK1.2, U11.10 (OUTN)
unnamed: ED4.1, SPK1.1, U11.9 (OUTP)
unnamed: R9.2, U11.4 (SD_MODE#)
VCC-3V3-P: C5.1, C9.1, U9.5 (VDD), U10.2 (LR), U10.5 (VDD); also elsewhere on the board
VCC-5V-REG: C10.1, C11.1, U11.7 (VDD), U11.8 (VDD); also elsewhere on the board

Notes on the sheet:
Microphone Input
RIGHT CHANNEL SELECT
SPEAKER MIC
LEFT CHANNEL SELECT
12dB

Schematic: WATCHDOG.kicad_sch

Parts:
C56: 100nF/50V; C_0603_1608Metric; Part Description 0.1uF 10% 16V Ceramic Capacitor X7R 040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; LCSC C1591
R135: 100k; R_0603_1608Metric
U2: TPS3828-33DBVR; Manufacturer Part TPS3828-33DBVR; LCSC C20032

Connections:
/MCU-STM32/WDO: U2.4 (WDI); also elsewhere on the board
/MCU-STM32/~JTAG_RST: R135.2, U2.3 (MR#); also elsewhere on the board
/MCU-STM32/~STM32_RST: U2.1 (RESET#); also elsewhere on the board
GND: C56.2, U2.2 (GND); also elsewhere on the board
VCC-3V3-P: C56.1, R135.1, U2.5 (VDD); also elsewhere on the board

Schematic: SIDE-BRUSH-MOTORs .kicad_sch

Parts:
C92: 100nF/50V; C_0603_1608Metric; VOLTAGERATE 50V; MANUFACTURINGPARTNUMBER *; LCSC C1591
C138: 10uF/25V; C_0603_1608Metric; LCSC C96446
D22: 1N4007; SOD123; VOLTAGERATE *; MANUFACTURINGPARTNUMBER *; LCSC C2892681
R55, R57: 100k; R_0603_1608Metric
R88: 0.2R/10W; R_2512_6332Metric; VOLTAGERATE *; MANUFACTURINGPARTNUMBER *; LCSC C5375488
R110: 10k; R_0603_1608Metric; VOLTAGERATE *; MANUFACTURINGPARTNUMBER *
SIDE_BRUSH1: ZX-ZH1_5-2PWT; Manufacturer Part ZX-ZH1.5-2PWT; LCSC C19272405
U18: DRV8870DDAR; VOLTAGERATE *; MANUFACTURINGPARTNUMBER *; LCSC C86590

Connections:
/MCU-STM32/SIDE-BRUSH-CURRENT-ADC: D22.1 (A), R110.1; also elsewhere on the board
/MCU-STM32/SIDE-BRUSH-IN1: R55.1, U18.3 (IN1); also elsewhere on the board
/MCU-STM32/SIDE-BRUSH-IN2: R57.1, U18.2 (IN2); also elsewhere on the board
GND: C92.1, C138.2, D22.2 (K), R55.2, R57.2, R88.1, SIDE_BRUSH1.3, SIDE_BRUSH1.4, U18.1 (GND), U18.9 (EP); also elsewhere on the board
unnamed: R88.2, R110.2, U18.7 (ISEN)
unnamed: SIDE_BRUSH1.1, U18.6 (OUT1)
unnamed: SIDE_BRUSH1.2, U18.8 (OUT2)
VCC-3V3-P: U18.4 (VREF); also elsewhere on the board
VM-VBAT: C92.2, C138.1, U18.5 (VM); also elsewhere on the board

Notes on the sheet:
SIDE-BRUSH MOTOR CONTROL

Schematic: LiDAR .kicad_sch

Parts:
C139: 10uF/25V; C_0603_1608Metric; LCSC C96446
D10: SS34; D_SMA; VOLTAGERATE *; MANUFACTURINGPARTNUMBER *; LCSC C22448055
Q20: AO3400; SOT23-3D; VOLTAGERATE *; MANUFACTURINGPARTNUMBER *; LCSC C20628874
R65: 1k; R_0603_1608Metric
R116, R118: 100k; R_0603_1608Metric; VOLTAGERATE *; MANUFACTURINGPARTNUMBER *
U3: HC-PM254-5_0H-2X4PS-02A; Manufacturer Part HC-PM254-5.0H-2x4PS-02A; LCSC C42163132

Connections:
/LiDAR/LIDAR_EN: R118.2, U3.6; also elsewhere on the board
/LiDAR/LiDAR-MOTOR-CTRL: Q20.1 (G), R116.2, U3.8; also elsewhere on the board
/LiDAR/LiDAR-RXD: R65.1; also elsewhere on the board
/LiDAR/LiDAR-TXD: U3.5; also elsewhere on the board
GND: C139.2, Q20.2 (S), R116.1, R118.1, U3.7; also elsewhere on the board
unnamed: D10.1 (A), Q20.3 (D), U3.4
unnamed: R65.2, U3.3
VCC-5V-REG: C139.1, D10.2 (K), U3.1, U3.2; also elsewhere on the board

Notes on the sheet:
LiDAR

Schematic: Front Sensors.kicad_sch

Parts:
C6, C19, C90, C91, C123: 10uF/25V; C_0603_1608Metric; LCSC C96446
IR-F1, IR-F2: ZX-ZH1_5-4PWT; Manufacturer Part ZX-ZH1.5-4PWT; LCSC C19272407
LIGHT1: ZX-ZH1_5-2PWT; Manufacturer Part ZX-ZH1.5-2PWT; LCSC C19272405
Q2: 2302V; Manufacturer Part 2302V; LCSC C7431443
R2, R7, R61, R62: 47k; R_0603_1608Metric
R5, R6: 2.2k; R_0603_1608Metric
R54: 100k; R_0603_1608Metric
VL-L1: ZX-ZH1_5-7PWT; Manufacturer Part ZX-ZH1.5-7PWT; LCSC C19272410
VL-R1: ZX-ZH1_5-7PWT; Manufacturer Part ZX-ZH1.5-7PWT; LCSC C19272410

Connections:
/CM5-GPIO/GPIO16: VL-R1.7; also elsewhere on the board
/CM5-GPIO/GPIO17: R2.1, VL-L1.3, VL-R1.3; also elsewhere on the board
/CM5-GPIO/GPIO25: R61.2, VL-L1.6; also elsewhere on the board
/CM5-GPIO/GPIO26: R62.2, VL-L1.7; also elsewhere on the board
/CM5-GPIO/GPIO27: R7.2, VL-R1.6; also elsewhere on the board
/CM5-GPIO/SCL1: R6.2, VL-L1.5, VL-R1.5; also elsewhere on the board
/CM5-GPIO/SDA1: R5.2, VL-L1.4, VL-R1.4; also elsewhere on the board
/FRONT SENSORS/IR-F-RX1: IR-F1.4; also elsewhere on the board
/FRONT SENSORS/IR-F-RX2: IR-F2.4; also elsewhere on the board
/FRONT SENSORS/LIGHT-ON: Q2.1 (G), R54.1; also elsewhere on the board
GND: C6.2, C19.2, C90.2, C91.2, C123.2, IR-F1.2, IR-F1.3, IR-F1.5, IR-F1.6, IR-F2.2, IR-F2.3, IR-F2.5, IR-F2.6, LIGHT1.3, LIGHT1.4, Q2.2 (S), R2.2, R54.2, VL-L1.2, VL-L1.8, VL-L1.9, VL-R1.2, VL-R1.8, VL-R1.9; also elsewhere on the board
unnamed: C6.1, VL-L1.1
unnamed: C123.1, LIGHT1.2, Q2.3 (D)
VCC-3V3-P: C19.1, C90.1, C91.1, IR-F1.1, IR-F2.1, LIGHT1.1, R5.1, R6.1, R7.1, R61.1, R62.1, VL-R1.1; also elsewhere on the board

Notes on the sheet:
SCL
VDD
LPn
I2C-RST
IR LIGHT
SDA
RECEIVER
INT
https://thepihut.com/products/850nm-ir-led-modules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
GND
2 IR RECEIVERS
2x VL53L7CX

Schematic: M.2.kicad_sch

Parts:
C45: 10uF/25V; C_0603_1608Metric; Manufacturer_Part_Number GRM21BR61H106KE43L; LCSC C96446
C50: 100nF/50V; C_0603_1608Metric; Manufacturer_Part_Number CL10B104KB8NNNC; LCSC C1591
J2: 1-2199119-5; TE_1-2199119-5; LCSC C574849
M2_ACT1: YLED0603B; Manufacturer Part YLED0603B; LCSC C19171394
MP1, MP2, MP3, MP4: M3 x 1.5mm; MountingHole_3.2mm_M3_Pad; PART-NUMBER 9774015360R
R79: 1k; R_0603_1608Metric
Y1: ASEK-32.768KHZ-LRT; XTAL_ASEK-32.768KHZ-LRT; PARTREV 01-11-22; LCSC C2650753

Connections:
/CM5-HIGHSPEED/PCIE_CLK_N: J2.53; also elsewhere on the board
/CM5-HIGHSPEED/PCIE_CLK_P: J2.55; also elsewhere on the board
/CM5-HIGHSPEED/PCIE_CLK_nREQ: J2.52; also elsewhere on the board
/CM5-HIGHSPEED/PCIE_RX_N: J2.43; also elsewhere on the board
/CM5-HIGHSPEED/PCIE_RX_P: J2.41; also elsewhere on the board
/CM5-HIGHSPEED/PCIE_TX_N: J2.49; also elsewhere on the board
/CM5-HIGHSPEED/PCIE_TX_P: J2.47; also elsewhere on the board
/CM5-HIGHSPEED/PCIE_nRST: J2.50; also elsewhere on the board
/CM5-HIGHSPEED/PCIE_nWAKE: J2.54; also elsewhere on the board
GND: C45.2, C50.2, J2.1, J2.3, J2.9, J2.15, J2.21, J2.27, J2.33, J2.39, J2.45, J2.51, J2.57, J2.71, J2.73, J2.75, J2.SH1 (SHIELD), J2.SH2 (SHIELD), MP1.1, MP2.1, MP3.1, MP4.1, Y1.2 (GND/CASE); also elsewhere on the board
unnamed: J2.10, M2_ACT1.2 (K)
unnamed: J2.68, Y1.3 (OUTPUT)
unnamed: M2_ACT1.1 (A), R79.2
VCC3V3_M2: C45.1, C50.1, J2.2, J2.4, J2.12, J2.14, J2.16, J2.18, J2.70, J2.72, J2.74, R79.1, Y1.1 (TRI-STATE), Y1.4 (VDD); also elsewhere on the board

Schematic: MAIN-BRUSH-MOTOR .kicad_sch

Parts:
C103: 100nF/50V; C_0603_1608Metric; VOLTAGERATE 50V; MANUFACTURINGPARTNUMBER *; LCSC C1591
C134: 10uF/25V; C_0603_1608Metric; LCSC C96446
MAIN_BRUSH1: ZX-ZH1_5-2PWT; Manufacturer Part ZX-ZH1.5-2PWT; LCSC C19272405
R3, R4: 100k; R_0603_1608Metric
R112: 0.2R/10W; R_2512_6332Metric; VOLTAGERATE *; MANUFACTURINGPARTNUMBER *; LCSC C5375488
U20: DRV8870DDAR; VOLTAGERATE *; MANUFACTURINGPARTNUMBER *; LCSC C86590

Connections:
/MAIN-BRUSH MOTOR/MAIN-BRUSH-CURRENT-ADC: R112.2, U20.7 (ISEN); also elsewhere on the board
/MAIN-BRUSH MOTOR/MAIN-BRUSH-IN1: R3.1, U20.3 (IN1); also elsewhere on the board
/MAIN-BRUSH MOTOR/MAIN-BRUSH-IN2: R4.1, U20.2 (IN2); also elsewhere on the board
GND: C103.1, C134.2, MAIN_BRUSH1.3, MAIN_BRUSH1.4, R3.2, R4.2, R112.1, U20.1 (GND), U20.9 (EP); also elsewhere on the board
unnamed: MAIN_BRUSH1.1, U20.6 (OUT1)
unnamed: MAIN_BRUSH1.2, U20.8 (OUT2)
VCC-3V3-P: U20.4 (VREF); also elsewhere on the board
VM-VBAT: C103.2, C134.1, U20.5 (VM); also elsewhere on the board

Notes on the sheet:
MAIN BUSH MOTOR CONTROL

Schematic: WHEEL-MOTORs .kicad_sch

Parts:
C84, C88: 100nF/50V; C_0603_1608Metric; VOLTAGERATE 50V; MANUFACTURINGPARTNUMBER *; LCSC C1591
C135, C136: 10uF/25V; C_0603_1608Metric; LCSC C96446
C142, C143: 100nF/50V; C_0603_1608Metric; Manufacturer_Part_Number CL10B104KB8NNNC; LCSC C1591
MOT_WHEEL_L1: ZX-ZH1_5-7PWT; Manufacturer Part ZX-ZH1.5-7PWT; LCSC C19272410
MOT_WHEEL_R1: ZX-ZH1_5-7PWT; Manufacturer Part ZX-ZH1.5-7PWT; LCSC C19272410
R11, R17, R20, R27: 100k; R_0603_1608Metric
R49, R50, R51, R52: 10k; R_0603_1608Metric
R83, R84: 0.2R/10W; R_2512_6332Metric; VOLTAGERATE *; MANUFACTURINGPARTNUMBER *; LCSC C5375488
U14, U15: DRV8870DDAR; VOLTAGERATE *; MANUFACTURINGPARTNUMBER *; LCSC C86590

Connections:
/MCU-STM32/WHEEL-M-L-F-ADC: R84.2, U15.7 (ISEN); also elsewhere on the board
/MCU-STM32/WHEEL-M-LEFT-DROP: MOT_WHEEL_L1.7, R50.2; also elsewhere on the board
/MCU-STM32/WHEEL-M-LEFT-ENCODE-A: MOT_WHEEL_L1.4, R52.2; also elsewhere on the board
/MCU-STM32/WHEEL-M-LEFT-IN1: R20.1, U15.3 (IN1); also elsewhere on the board
/MCU-STM32/WHEEL-M-LEFT-IN2: R27.1, U15.2 (IN2); also elsewhere on the board
/MCU-STM32/WHEEL-M-R-F-ADC: R83.2, U14.7 (ISEN); also elsewhere on the board
/MCU-STM32/WHEEL-M-RIGHT-DROP: MOT_WHEEL_R1.7, R49.2; also elsewhere on the board
/MCU-STM32/WHEEL-M-RIGHT-ENCODE-A: MOT_WHEEL_R1.4, R51.2; also elsewhere on the board
/MCU-STM32/WHEEL-M-RIGHT-IN1: R11.1, U14.3 (IN1); also elsewhere on the board
/MCU-STM32/WHEEL-M-RIGHT-IN2: R17.1, U14.2 (IN2); also elsewhere on the board
GND: C84.1, C88.1, C135.2, C136.2, C142.2, C143.2, MOT_WHEEL_L1.3, MOT_WHEEL_L1.6, MOT_WHEEL_L1.8, MOT_WHEEL_L1.9, MOT_WHEEL_R1.3, MOT_WHEEL_R1.6, MOT_WHEEL_R1.8, MOT_WHEEL_R1.9, R11.2, R17.2, R20.2, R27.2, R83.1, R84.1, U14.1 (GND), U14.9 (EP), U15.1 (GND), U15.9 (EP); also elsewhere on the board
unnamed: MOT_WHEEL_R1.1, U14.6 (OUT1)
unnamed: MOT_WHEEL_R1.2, U14.8 (OUT2)
unnamed: MOT_WHEEL_L1.1, U15.6 (OUT1)
unnamed: MOT_WHEEL_L1.2, U15.8 (OUT2)
VCC-3V3-P: C142.1, C143.1, MOT_WHEEL_L1.5, MOT_WHEEL_R1.5, R49.1, R50.1, R51.1, R52.1, U14.4 (VREF), U15.4 (VREF); also elsewhere on the board
VM-VBAT: C84.2, C88.2, C135.1, C136.1, U14.5 (VM), U15.5 (VM); also elsewhere on the board

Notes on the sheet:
WHEEL MOTOR CONTROL

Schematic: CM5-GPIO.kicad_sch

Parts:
BOOT1: Conn_01x02_Pin; PinHeader_1x02_P2.54mm_Vertical; LCSC C32713268
C1, C2, C4: 100nF/50V; C_0603_1608Metric; Part Description 0.1uF 10% 16V Ceramic Capacitor X7R 040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; LCSC C1591
C3: 10uF/25V; C_0603_1608Metric; Part Description 10uF 10% 10V Ceramic Capacitor X7R 0805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; LCSC C96446
CM_ACT1: YLED0603B; Manufacturer Part YLED0603B; LCSC C19171394
CM_PWR1: YLED0603B; Manufacturer Part YLED0603B; LCSC C19171394
CONSOLE1: Conn_01x05_Pin; PinHeader_1x05_P2.54mm_Vertical; LCSC C42431835
H1: PM254-2-06-S-8_5; Manufacturer Part PM254-2-06-S-8.5; LCSC C3975151
Module1: ComputeModule5-CM5; Raspberry-Pi-5-Compute-Module; Part Description 100 Position Connector Receptacle, Cent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; LCSC 2X C6932320
Q10: 2302V; Manufacturer Part 2302V; LCSC C7431443
R82, R85: 1k; R_0603_1608Metric
R142: 10k; R_0603_1608Metric
SDCARD2: 1040310811; Manufacturer Part 1040310811; LCSC C585350
U6: RT9742GGJ5; Manufacturer Part RT9742GGJ5; LCSC C250547

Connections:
+3.3VP: C1.1, Module1.78 (GPIO_VREF(1.8v/3.3v_Input)), Module1.84 (+3.3v_(Output)), Module1.86 (+3.3v_(Output)), R82.1, R85.1, R142.1, U6.5 (VIN); also elsewhere on the board
/CAMERA/CAM_GPIO0: Module1.100 (CAM_GPIO1); also elsewhere on the board
/CAMERA/CAM_GPIO1: Module1.97 (CAM_GPIO0); also elsewhere on the board
/CAMERA/ID_SC: Module1.35 (ID_SC); also elsewhere on the board
/CAMERA/ID_SD: Module1.36 (ID_SD); also elsewhere on the board
/CAMERA/SCL0: Module1.80 (SCL0); also elsewhere on the board
/CAMERA/SDA0: Module1.82 (SDA0); also elsewhere on the board
/CM5-GPIO/CONSOLE_RXD: CONSOLE1.4, Module1.51 (GPIO15)
/CM5-GPIO/CONSOLE_TXD: CONSOLE1.5, Module1.55 (GPIO14)
/CM5-GPIO/GPIO06: Module1.30 (GPIO6); also elsewhere on the board
/CM5-GPIO/GPIO7: H1.2, Module1.37 (GPIO7)
/CM5-GPIO/GPIO8: H1.1, Module1.39 (GPIO8)
/CM5-GPIO/GPIO9: H1.4, Module1.40 (GPIO9)
/CM5-GPIO/GPIO10: H1.3, Module1.44 (GPIO10)
/CM5-GPIO/GPIO11: H1.6, Module1.38 (GPIO11)
/CM5-GPIO/GPIO12: H1.9, Module1.31 (GPIO12)
/CM5-GPIO/GPIO13: H1.10, Module1.28 (GPIO13)
/CM5-GPIO/GPIO16: Module1.29 (GPIO16); also elsewhere on the board
/CM5-GPIO/GPIO17: Module1.50 (GPIO17); also elsewhere on the board
/CM5-GPIO/GPIO22: H1.5, Module1.46 (GPIO22)
/CM5-GPIO/GPIO23: H1.8, Module1.47 (GPIO23)
/CM5-GPIO/GPIO24: H1.7, Module1.45 (GPIO24)
/CM5-GPIO/GPIO25: Module1.41 (GPIO25); also elsewhere on the board
/CM5-GPIO/GPIO26: Module1.24 (GPIO26); also elsewhere on the board
/CM5-GPIO/GPIO27: Module1.48 (GPIO27); also elsewhere on the board
/CM5-GPIO/I2S_DOUT: Module1.25 (GPIO21); also elsewhere on the board
/CM5-GPIO/PMIC_EN: Module1.99 (PMIC_ENABLE); also elsewhere on the board
/CM5-GPIO/RUN_PG: Module1.92 (PWR_BUT); also elsewhere on the board
/CM5-GPIO/SCL1: Module1.56 (GPIO3); also elsewhere on the board
/CM5-GPIO/SDA1: Module1.58 (GPIO2); also elsewhere on the board
/CM5-GPIO/SD_CLK: Module1.57 (SD_CLK), SDCARD2.5 (CLK)
/CM5-GPIO/SD_CMD: Module1.62 (SD_CMD), SDCARD2.3 (CMD)
/CM5-GPIO/SD_DAT0: Module1.63 (SD_DAT0), SDCARD2.7 (DAT0)
/CM5-GPIO/SD_DAT1: Module1.67 (SD_DAT1), SDCARD2.8 (DAT1)
/CM5-GPIO/SD_DAT2: Module1.69 (SD_DAT2), SDCARD2.1 (DAT2)
/CM5-GPIO/SD_DAT3: Module1.61 (SD_DAT3), SDCARD2.2 (CD/DAT3)
/CM5-GPIO/SD_PWR_ON: Module1.75 (SD_PWR_ON), R142.2, U6.4 (EN/EN#)
/CM5-GPIO/UART2_RX: Module1.34 (GPIO5); also elsewhere on the board
/CM5-GPIO/UART2_TX: Module1.54 (GPIO4); also elsewhere on the board
/SPEAKER-MIC/BCLK: Module1.49 (GPIO18); also elsewhere on the board
/SPEAKER-MIC/DOUT: Module1.27 (GPIO20); also elsewhere on the board
/SPEAKER-MIC/LRCLK: Module1.26 (GPIO19); also elsewhere on the board
GND: BOOT1.2, C1.2, C2.2, C3.2, C4.2, CONSOLE1.1, H1.12, Module1.1 (GND), Module1.2 (GND), Module1.7 (GND), Module1.8 (GND), Module1.13 (GND), Module1.14 (GND), Module1.22 (GND), Module1.23 (GND), Module1.32 (GND), Module1.33 (GND), Module1.42 (GND), Module1.43 (GND), Module1.52 (GND), Module1.53 (GND), Module1.59 (GND), Module1.60 (GND), Module1.65 (GND), Module1.66 (GND), Module1.71 (GND), Module1.74 (GND), Module1.98 (GND), Q10.2 (S), SDCARD2.6 (VSS), SDCARD2.9, SDCARD2.10, SDCARD2.11, SDCARD2.12, SDCARD2.13, SDCARD2.14, U6.2 (GND); also elsewhere on the board
unnamed: BOOT1.1, Module1.93 (nRPIBOOT)
unnamed: C2.1, Module1.88 (+1.8v_(Output)), Module1.90 (+1.8v_(Output))
unnamed: CM_ACT1.1 (A), R85.2
unnamed: CM_ACT1.2 (K), Module1.21 (LED_nACT)
unnamed: CM_PWR1.1 (A), R82.2
unnamed: CM_PWR1.2 (K), Q10.3 (D)
unnamed: Module1.95 (LED_nPWR), Q10.1 (G)
unnamed: C4.1, SDCARD2.4 (VDD), U6.1 (VOUT)
VCC3V3_M2: H1.11; also elsewhere on the board
VCC-5V-REG: C3.1, Module1.77 (+5v_(Input)), Module1.79 (+5v_(Input)), Module1.81 (+5v_(Input)), Module1.83 (+5v_(Input)), Module1.85 (+5v_(Input)), Module1.87 (+5v_(Input)); also elsewhere on the board

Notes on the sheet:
UART3_TX on the CM4
Compatible with TTL-234X-3V3 smart cable
UART3_RX on the CM4

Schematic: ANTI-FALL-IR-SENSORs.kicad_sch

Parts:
BUMP_CLIFF1: S16B-PHDSS_LF_SN; Manufacturer Part S16B-PHDSS(LF)(SN); LCSC C161675
Q5, Q6: 2302V; Manufacturer Part 2302V; LCSC C7431443
R30, R35: 330; R_0603_1608Metric
R38, R39, R41, R44: 10k; R_0603_1608Metric
R48, R53: 100k; R_0603_1608Metric

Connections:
/ANTI-FALL/ANTI-FALL-LEFT-DOWN-ADC: BUMP_CLIFF1.13, R41.1; also elsewhere on the board
/ANTI-FALL/ANTI-FALL-LEFT-UP-ADC: BUMP_CLIFF1.5, R38.1; also elsewhere on the board
/ANTI-FALL/ANTI-FALL-RIGHT-DOWN-ADC: BUMP_CLIFF1.14, R44.1; also elsewhere on the board
/ANTI-FALL/ANTI-FALL-RIGHT-UP-ADC: BUMP_CLIFF1.6, R39.1; also elsewhere on the board
/ANTI-FALL/BUMPER_LED_EN: Q5.1 (G), R53.1; also elsewhere on the board
/ANTI-FALL/CLIFF_LED_EN: Q6.1 (G), R48.1; also elsewhere on the board
/ANTI-FALL/L1-: BUMP_CLIFF1.1, Q5.3 (D)
/ANTI-FALL/LR-: BUMP_CLIFF1.15, Q6.3 (D)
/ANTI-FALL/R2+: BUMP_CLIFF1.2, R30.1
/ANTI-FALL/RR+: BUMP_CLIFF1.16, R35.1
GND: BUMP_CLIFF1.7, BUMP_CLIFF1.8, BUMP_CLIFF1.9, BUMP_CLIFF1.10, Q5.2 (S), Q6.2 (S), R38.2, R39.2, R41.2, R44.2, R48.2, R53.2; also elsewhere on the board
VCC-3V3-P: BUMP_CLIFF1.3, BUMP_CLIFF1.4, BUMP_CLIFF1.11, BUMP_CLIFF1.12; also elsewhere on the board
VCC-5V-REG: R30.2, R35.2; also elsewhere on the board

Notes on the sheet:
ANTI FALL SENSORs

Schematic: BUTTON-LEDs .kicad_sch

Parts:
HOME1: YLED0603B; Manufacturer Part YLED0603B; LCSC C19171394
PWR1: YLED0603B; Manufacturer Part YLED0603B; LCSC C19171394
R77, R78: 1k; R_0603_1608Metric
R120, R121: 1k; R_0603_1608Metric; VOLTAGERATE *; MANUFACTURINGPARTNUMBER *
SW1, SW2, SW3: TC-6601-5_0-260-8_3; Manufacturer Part TC-6601-5.0-260-8.3; LCSC C7528752

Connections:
/BUTTON-LED/CLEAN-BTN: R121.1, SW3.3, SW3.4; also elsewhere on the board
/BUTTON-LED/HOME-BTN: R120.1, SW2.3, SW2.4; also elsewhere on the board
/BUTTON-LED/LED-HOME: R77.1; also elsewhere on the board
/BUTTON-LED/LED-PWR: R78.1; also elsewhere on the board
/BUTTON-LED/POWER-BTN: SW1.3, SW1.4; also elsewhere on the board
GND: HOME1.2 (K), PWR1.2 (K), SW1.1, SW1.2, SW2.1, SW2.2, SW3.1, SW3.2; also elsewhere on the board
unnamed: HOME1.1 (A), R77.2
unnamed: PWR1.1 (A), R78.2
VCC-3V3-P: R120.2, R121.2; also elsewhere on the board

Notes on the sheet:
LEDs AND BUTTONs

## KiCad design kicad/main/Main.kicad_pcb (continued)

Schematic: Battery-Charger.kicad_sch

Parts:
BAT2: BATTERY; 436500412; Manufacturer Part 436500412; LCSC C563847
C47, C58: 330pF/25V; C_0603_1608Metric
C59, C61, C64, C65, C73: 100nF/50V; C_0603_1608Metric; LCSC C1591
C60, C66, C67, C68, C69, C70, C71, C72, C74, C76, C78, C80, C81, C82, C83, C94, C96, C97, C98, C99, C100: 10uF/25V; C_0603_1608Metric; LCSC C96446
C75, C79: 47nF/50V; C_0603_1608Metric
C77, C125, C126: 1nF/50V; C_0603_1608Metric
CN2: EV2400; A2543WV-4P; Manufacturer Part A2543WV-4P; LCSC C239364; not fitted
CONTACT_CHGR1: WAFER-PH2_0-4PWB; Manufacturer Part WAFER-PH2.0-4PWB; LCSC C3029442
D1, D2: TVS2200DRVR; Manufacturer Part TVS2200DRVR; LCSC C523793
D3: SMAJ18A_C148219; Manufacturer Part SMAJ18A; LCSC C148219
D29: 3V3-STAT; LED0603-B; VOLTAGERATE *; MANUFACTURINGPARTNUMBER *; LCSC C19171394
D34: TPD2EUSB30DRTR; SOTFL35P100X50-3N; MPN TPD2EUSB30DRTR; LCSC C97502
D39, D40: BZT52C12T-7; Manufacturer Part BZT52C12T-7; LCSC C507911
IC5: TPS25730DREFR; Manufacturer_Part_Number TPS25730DREFR; Mouser Part Number 595-TPS25730DREFR
L7: 1uH; GSM0420-1R0-M; Manufacturer Part GSM0420-1R0-M; LCSC C51933819
Q4, Q21: SQJ844AEP-T1_GE3; Manufacturer Part SQJ844AEP-T1_GE3; LCSC C727613
R37: 1k; R_0603_1608Metric; VOLTAGERATE *; MANUFACTURINGPARTNUMBER *
R60: 30.31k; R_0603_1608Metric
R75, R76, R100: 100; R_0805_2012Metric
R99: 215k; R_0603_1608Metric; Manufacturer Part RC0402FR-07215KL; LCSC C185443
R115, R128, R130, R133, R138, R139: 100k; R_0603_1608Metric
R127, R136, R137: 5.24k; R_0603_1608Metric
R129: 17.4k; R_0603_1608Metric; Manufacturer Part RC0402FR-0717K4L; LCSC C327366
R131: 20k; R_0603_1608Metric
R132: 10k; R_0603_1608Metric
R140: 1k; R_0603_1608Metric
U7: BQ25792RQMR; Manufacturer Part BQ25792RQMR; LCSC C2862876
USB2: USB4215-03-A_REVA; GCT_USB4215-03-A_REVA; MPN USB4215-03-A; LCSC C37616412

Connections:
/BATTERY-CHARGER/ADCIN1: IC5.2 (ADCIN1), R139.2, R140.1
/BATTERY-CHARGER/ADCIN2: IC5.3 (ADCIN2), R137.2, R138.1
/BATTERY-CHARGER/ADCIN3: IC5.5 (ADCIN3), R133.2, R136.1
/BATTERY-CHARGER/ADCIN4: IC5.7 (ADCIN4), R130.2, R131.1
/BATTERY-CHARGER/CC1: C47.2, IC5.28 (CC1), USB2.A5 (CC1)
/BATTERY-CHARGER/CC2: C58.2, IC5.29 (CC2), USB2.B5 (CC2)
/BATTERY-CHARGER/D+: D34.1 (D+), USB2.A6 (DP1), USB2.B6 (DP2); also elsewhere on the board
/BATTERY-CHARGER/D-: D34.2 (D-), USB2.A7 (DN1), USB2.B7 (DN2); also elsewhere on the board
/BATTERY-CHARGER/DRAIN: IC5.15 (DRAIN_1), IC5.30 (DRAIN_2), IC5.40 (DRAIN_3)
/BATTERY-CHARGER/ID: BAT2.3; also elsewhere on the board
/BATTERY-CHARGER/LDO3V3: C74.2, IC5.1 (LDO_3V3), R128.1, R130.1, R133.1, R137.1, R139.1
/BATTERY-CHARGER/NTC: BAT2.2, R60.2, R127.2, U7.16 (TS)
/BATTERY-CHARGER/P+/C+: BAT2.1, R100.2, U7.22 (BAT), U7.23 (BAT)
/BATTERY-CHARGER/REGN: C70.2, D29.1, R115.2, R127.1, U7.5 (REGN)
/BATTERY-CHARGER/SCL: CN2.2, IC5.9 (I2CT_SCL), U7.14 (SCL); also elsewhere on the board
/BATTERY-CHARGER/SDA: CN2.3, IC5.8 (I2CT_SDA), U7.15 (SDA); also elsewhere on the board
/BATTERY-CHARGER/VBUS: C61.2, C64.2, C65.2, C66.2, D2.4 (IN), D2.5 (IN), D2.6 (IN), IC5.23 (VBUS_IN_1), IC5.24 (VBUS_IN_2), IC5.25 (VBUS_IN_3), IC5.32 (VBUS_1), IC5.33 (VBUS_2), IC5.42 (VBUS_IN_4), IC5.43 (VBUS_3), USB2.A4_B9 (VBUS_A), USB2.B4_A9 (VBUS_B)
/BATTERY-CHARGER/VOUT_PD: C60.1, C71.2, C72.2, C73.2, IC5.20 (PPHV_1), IC5.21 (PPHV_2), IC5.22 (PPHV_3), IC5.41 (PPHV_4), Q21.6 (D1), U7.9 (VAC1)
/BATTERY-CHARGER/~INT: R132.1, U7.21 (INT#); also elsewhere on the board
BAT-VCC: C83.1, C96.2, C97.2, C98.2, C99.2, C100.2, D3.1, U7.25 (SYS); also elsewhere on the board
GND: BAT2.4, BAT2.5, BAT2.6, C47.1, C58.1, C59.1, C60.2, C61.1, C64.1, C65.1, C66.1, C67.1, C68.1, C69.2, C70.1, C71.1, C72.1, C73.1, C74.1, C76.1, C77.1, C78.2, C80.1, C81.1, C82.1, C83.2, C94.2, C96.1, C97.1, C98.1, C99.1, C100.1, CN2.1, CONTACT_CHGR1.1, CONTACT_CHGR1.2, CONTACT_CHGR1.5, CONTACT_CHGR1.6, D1.1 (GND), D1.2 (GND), D1.3 (GND), D1.7 (GND), D2.1 (GND), D2.2 (GND), D2.3 (GND), D2.7 (GND), D3.2, D34.3 (GND), IC5.11 (GND_1), IC5.12 (GND_2), IC5.14 (GND_3), IC5.16 (GND_4), IC5.17 (GND_5), IC5.31 (GND_6), IC5.34 (GND_7), IC5.35 (GND_8), IC5.39 (GND_9), IC5.44 (GND_10), R60.1, R99.1, R129.1, R131.2, R136.2, R138.2, R140.2, U7.13 (CE#), U7.27 (GND), USB2.A1_B12 (GND_A), USB2.B1_A12 (GND_B), USB2.SH1 (SHIELD), USB2.SH2 (SHIELD__1), USB2.SH3 (SHIELD__2), USB2.SH4 (SHIELD__3); also elsewhere on the board
unnamed: D29.2, R37.2
unnamed: C125.1, D39.2 (A), Q4.1 (S1), Q4.3 (S2)
unnamed: C125.2, D39.1 (K), Q4.2 (G1), Q4.4 (G2), R75.1
unnamed: C126.1, D40.2 (A), Q21.1 (S1), Q21.3 (S2)
unnamed: C126.2, D40.1 (K), Q21.2 (G1), Q21.4 (G2), R76.1
unnamed: C76.2, IC5.4 (LDO_1V5)
unnamed: IC5.18 (~FAULT_IN), R128.2
unnamed: C94.1, CONTACT_CHGR1.3, CONTACT_CHGR1.4, D1.4 (IN), D1.5 (IN), D1.6 (IN), Q4.5 (D2), U7.8 (VAC2)
unnamed: R76.2, U7.11 (ACDRV1)
unnamed: R75.2, U7.10 (ACDRV2)
unnamed: R100.1, U7.18 (BATP)
unnamed: C75.1, U7.4 (BTST1)
unnamed: C79.1, U7.19 (BTST2)
unnamed: R99.2, R115.1, U7.17 (ILIM_HIZ)
unnamed: C78.1, C80.2, C81.2, C82.2, U7.29 (PMID)
unnamed: R129.2, U7.20 (PROG)
unnamed: C77.2, U7.24 (SDRV)
unnamed: R37.1, U7.1 (STAT)
unnamed: C75.2, L7.1, U7.28 (SW1)
unnamed: C79.2, L7.2, U7.26 (SW2)
VCC-3V3-P: C59.2, IC5.38 (VIN_3V3), R132.2; also elsewhere on the board
VCC-CHARG: C67.2, C68.2, C69.1, Q4.6 (D1), Q21.5 (D2), U7.2 (VBUS), U7.3 (VBUS); also elsewhere on the board

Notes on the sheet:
BATTERY CONNECTOR
I Limit = 5 Amp
OPTIONAL
.I2C Address = 0x20 .Min Voltage= 5V .Max Voltage= 20V .Op Current= 1A .Max Current= 5A
Freq=1.5MHz
POWER DELIVERY
BATTERY CHARGER
Put the MCU into RESET mode if use EV2400 to debug the charger
4S/1Amp
NOTE : D+ , D_ are connected to CM4/5
NOTE : SDA,SCL,nINT are connected to MCU
USB-C

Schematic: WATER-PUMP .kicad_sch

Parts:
C105: 150pF/50V; C_0603_1608Metric; VOLTAGERATE 10V; MANUFACTURINGPARTNUMBER *; not fitted
C133: 10uF/25V; C_0603_1608Metric; LCSC C96446
D6: SS34; D_SMA; VOLTAGERATE *; MANUFACTURINGPARTNUMBER *; LCSC C22448055
PUMP1: ZX-ZH1_5-2PWT; Manufacturer Part ZX-ZH1.5-2PWT; LCSC C19272405
Q7: 2302V; Manufacturer Part 2302V; LCSC C7431443
Q8: AO3401; SOT23-3D; VOLTAGERATE *; MANUFACTURINGPARTNUMBER *; LCSC C15127
R25, R81: 10k; R_0603_1608Metric; VOLTAGERATE *; MANUFACTURINGPARTNUMBER *
R43: 100k; R_0603_1608Metric
R47: 20k; R_0603_1608Metric

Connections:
/MCU-STM32/WATER-PUMP-SENSE-ADC: R47.1, R81.2; also elsewhere on the board
/MCU-STM32/WATER-PUMPU-CTRL: Q7.1 (G), R43.1; also elsewhere on the board
GND: C105.1, C133.2, D6.1 (A), PUMP1.2, PUMP1.3, PUMP1.4, Q7.2 (S), R43.2, R47.2; also elsewhere on the board
unnamed: C105.2, C133.1, D6.2 (K), PUMP1.1, Q8.3 (D), R81.1
unnamed: Q7.3 (D), Q8.1 (G), R25.1
VM-5V: Q8.2 (S), R25.2; also elsewhere on the board

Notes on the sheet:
5V MOTOR
WATER PUMP MOTOR CONTROL

Board: 4 copper layers, 349 parts (204 on the bottom side), 288 nets, no tracks yet.

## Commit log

2026-07-03 Publish RK3562 + STM32G070 I/O board reference schematic (PDF)
    Add the schematic PDF (metadata-branded) and a README. Editable Altium
    source is held back for now; PDF is an unvalidated reference for review.
2026-07-07 Move RK schematic to docs
2026-07-07 Added PCB architecture specs
    Added architecture notes detailing the separation of compute and control in consumer vacuums, including MCU and CPU responsibilities, safety measures, and component specifications for the OOMWOO proj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
2026-07-08 Add RK3562 board as reference
    [ANTI-FALL-IR-SENSORs.SchDoc, BMS-SYSTEM-POWER.SchDoc, BOM-Controller-RK3562 - 2026-03-21-JLCPCB.xlsx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]
2026-07-12 Converted Altium to KiCad
    [ANTI-FALL-IR-SENSORs.kicad_sch, BMS-SYSTEM-POWER.kicad_sch, BUTTON-LEDs .kicad_sch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]
2026-07-13 Revise GPIO.md for OOMWOO I/O Board specs
    Updated GPIO documentation to reflect OOMWOO I/O Board specifications and added details about motors.
2026-07-15 Clean up I/O board docs and spec notes
2026-07-17 Battery charging
    [ANTI-FALL-IR-SENSORs.kicad_sch, BMS-SYSTEM-POWER.kicad_sch, Battery-Charger.kicad_sch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]
2026-07-18 Update power specifications for robot and dock
    Expanded specifications for the robot and dock power systems, including input requirements and charging behavior.
2026-07-18 Update MSD-G-V1 suction fan description
2026-07-20 Revise pump specifications in SPEC.md
    Updated pump specifications to use a 6V DC motor with adjustable settings.
2026-07-20 Added Pi CM4/CM5
    [BMS-SYSTEM-POWER.kicad_sch, Battery-Charger.kicad_sch, CM5-GPIO.kicad_sch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]
2026-07-20 Clarify I/O board specifications in README
    Change MCU to STM32G473VCT6; add firmware link
2026-07-23 ci: generate KiCad outputs on every PR; stop committing build outputs
    Add a GitHub Actions workflow (.github/workflows/ci.yaml) that regenerates
    the KiCad I/O board's outputs from source on every pull request and push to
    main and uploads them as build artifacts, and stop tracking the
    KiCad-generated files that were previously committed.
    Workflow uses actions-for-kicad/kicad-actions (KiCad 10.0) across three
    jobs that run in parallel:
    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
2026-07-23 Removed Altium
    [ANTI-FALL-IR-SENSORs.SchDoc, BMS-SYSTEM-POWER.SchDoc, BOM-Controller-RK3562 - 2026-03-21-JLCPCB.xlsx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]
2026-07-24 Changed MCU to STM32G473VCT6
    [ANTI-FALL-IR-SENSORs.kicad_sch, BMS-SYSTEM-POWER.kicad_sch, BUTTON-LEDs .kicad_sch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]
2026-07-25 Fixed stale schematic PDF
2026-07-27 Cliff, bumper sensors pinout
2026-08-06 RTC clock, signal integrity
    [BMS-SYSTEM-POWER.kicad_sch, CM5-Highspeed.kicad_sch, MAIN-BRUSH-MOTOR .kicad_sch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]
2026-08-08 External RTC; IR light; side sensors
    [BMS-SYSTEM-POWER.kicad_sch, CM5-GPIO.kicad_sch, Front Sensors.kicad_sch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]
2026-08-09 Front, side sensors schematics
    [ANTI-FALL-IR-SENSORs.kicad_sch, BMS-SYSTEM-POWER.kicad_sch, BUTTON-LEDs .kicad_sch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]
2026-08-09 VL6180 as wall sensor
2026-08-09 ci: point KiCad jobs at kicad/main/ after board restructure
    b643b3b moved the main board from kicad/ into kicad/main/ (alongside the
    new front-sensors and side-sensors projects) but left the workflow paths
    on the old flat layout, so export/ERC/DRC all failed on a missing file.
    Also give the ERC and DRC uploads distinct artifact names. Both defaulted
    to "artifact", which collides within a run; that was masked by the jobs
    dying earlier on the bad paths.
2026-08-11 Side sensor VL6180
    [Front Sensor.kicad_sch, IR sensor.kicad_sch, Main.kicad_pcb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]
2026-08-11 ci: point at the renamed main KiCad project (oomwoo-kicad -> Main)
    Commit 5f76bd0 ("Side sensor VL6180") renamed kicad/main/oomwoo-kicad.{kicad_sch,
    kicad_pcb} to Main.{kicad_sch,kicad_pcb}, but ci.yaml still referenced the old
    names, so the KiCad action failed to load the schematic/PCB and ERC/DRC/Export
    produced no report -- then upload-artifact failed with if-no-files-found: error.
    Update schematic_file_name / pcb_file_name to the new Main.* paths. Artifact
    output names (oomwoo-kicad-*) are unchanged.
2026-08-15 Charging-only dock schematic
    [Charging Dock.kicad_pcb, Charging Dock.kicad_sch, IR Beacon.kicad_sch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]
2026-08-23 Fix edge cut; no-CM STEP
    [ANTI-FALL-IR-SENSORs.kicad_sch, BMS-SYSTEM-POWER.kicad_sch, BUTTON-LEDs .kicad_sch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]
2026-09-01 Suction fans pinout
    Updated specifications for various suction fans, including pinouts and voltage ratings.
2026-09-02 Brought up drive wheels, measured currents
    Updated specifications for the main brush and suction fan, including voltage and current details.
2026-09-02 Add cliff sensors section to SPEC.md
    Added section on cliff sensors with connector details.
2026-09-03 SPEC: motors table carries the measured currents, TODOs dropped
    The table still held the original guesses while the bench measurements sat
    further down the same file, so it contradicted itself - and the drive-wheel
    guess (3.5A stall) happened to equal the main brush's measured stall, which
    is a good way to mis-size a driver. Drive wheel, suction fan and main brush
    now carry the measured no-load/stall figures. Side brush is left explicitly
    "estimated (not yet measured)" rather than dropping its marker, so an
    unverified number is not mistaken for a measured one.
2026-09-05 Carpet sensor driver
    Added details about carpet sensors, including sourcing notes and driving instructions.
2026-09-05 Schematic fixes, 1st round of review
    [ANTI-FALL-IR-SENSORs.kicad_sch, BMS-SYSTEM-POWER.kicad_sch, BUTTON-LEDs .kicad_sch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]

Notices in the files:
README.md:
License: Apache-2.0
